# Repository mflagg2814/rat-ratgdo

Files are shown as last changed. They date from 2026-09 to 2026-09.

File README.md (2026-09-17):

# XIAO ESP32-C6 / ESP32-C5 board

> [!WARNING]
> **The XIAO ESP32-C6 board added in this fork has not been built or tested yet, and it is provided without support.** Use it at your own risk.

AI disclosure: Board layout is my own. AI was used for verification, documentation, schematic cleanup, and minor board cleanup.

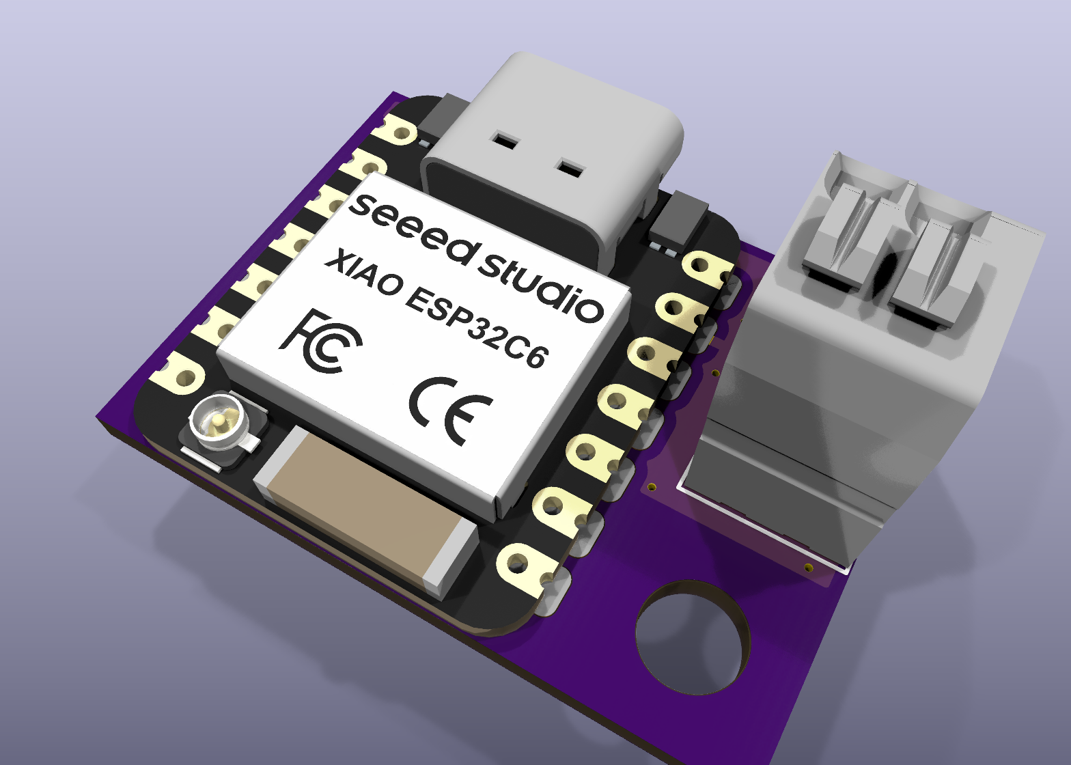
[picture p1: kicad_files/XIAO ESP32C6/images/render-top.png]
3D render of the XIAO ESP32-C6 board


[`kicad_files/XIAO ESP32C6`](kicad_files/XIAO%20ESP32C6) is a small Security+ 2.0 interface for the ESPHome `secplus_gdo` component, built around a surface-mounted Seeed XIAO ESP32-C6. Compared with the [D1 Mini - ESP32](kicad_files/D1%20Mini%20-%20ESP32) board it is based on:

- **MCU:** a XIAO ESP32-C6 replaces the D1 Mini ESP32. TX is on GPIO22 (D4) and RX on GPIO18 (D10). As before, the module is powered from its own USB port. The same footprint and pinout also accept a Seeed XIAO ESP32-C5 (see the [board README](kicad_files/XIAO%20ESP32C6/README.md#xiao-esp32-c5-compatibility) for the C5 substitutions).
- **RX:** a 10k pull-up to 3V3 is added, because the firmware does not enable an internal one.
- **Values:** the TX GPIO pulldown is 4.7k (was 10k), and the RED-to-ground bias is 100k (was 10k).
- **Protection:** a 15 V unidirectional TVS is added on the RED line.
- **Obstruction:** the black-wire sensing circuit is removed, since obstruction status is read from the serial protocol.
- **Terminal:** A single 2-pole WAGO push-button terminal replaces the 3-pole connector options. Accepts 20-24 AWG.

The folder includes a [BOM](kicad_files/XIAO%20ESP32C6/BOM.md) with DigiKey part numbers, a [schematic PDF](kicad_files/XIAO%20ESP32C6/c6gdo-schematic.pdf), and a [README](kicad_files/XIAO%20ESP32C6/README.md) with the full list of changes and the reasoning behind them. The project needs KiCad 10 and contains its own symbol, footprint and 3D-model libraries.

## XIAO ESP32-C5 compatibility
This board was designed for the XIAO ESP32-C6. The pinouts are also chosen for XIAO ESP32-C5 compatibility. I'm unsure of precedent for the GDO firmware- it may or may not function on C5.

## Firmware
Intended for use with SecPlus GDO firmware using the ESP-IDF framework.

An example ESPHome YAML would be an adaptation of `grgdov3-board-secplus-gdo-thread.yaml`, found [here](https://github.com/GelidusResearch/grgdo). Note that you will at a minimum need to remap the UART pins and change the board/variant to match.

---

# rat-ratgdo
RAGE
AGAINST
THE
RATGDO



Credit and inspiration for this work goes to [@rlowens](https://github.com/rlowens) to let me know that there are other technical folks out there who needed this other than myself.

## Overview
This is an open source schematic for the ratgdo, based on the v2.5 [ratgdo](https://github.com/PaulWieland/ratgdo) PCB and code but installed using the [ESPHome fork](ESPHome%20vs%20native%20ratgdo.md) of ratgdo.  This project was created to allow people who need a ratgdo solution for their garage door opener but either cannot, or choose not to, source the solution from Paul Wieland. It also ensures that the PCB can be recreated as and when the project maintainer gives up on the project (much like Chamberlain themselves might do with their MyQ Cloud Service) and stops selling PCBs. 

### You are expected to know how to create the described circuit using your own prototyping skills.  That is, this project is for people who can solder well and know how to read schematics

The ***basic*** PCB schematic shown here in the Readme does not describe any circuitry other than the serial line garage door control and obstruction sensor.  All other optional features provided by ratgdo can be reverse engineered as needed, or may already be solved by one of the schematics the community has uploaded!

 As of January 2023, there are now multiple sources for commercially sold ratgdo boards.  **However if you want to buy a pre-made ratgdo setup, we recommend purchasing one [from Paul Wieland](https://github.com/PaulWieland/ratgdo) so as to reward the original creator.**

PCB Link
_Simple basic schematic for a Wemos D1 Mini based module_

See images of a [working breadboard prototype](images/Breadboard_working.png) and the [subsequent soldered prototype using a D1 shield](images/Simple%20prototype%20using%20D1%20shield.jpg).  Both of these prototypes are using 2n7000 MOSFETs exclusively, but that is because they are prototypes and whether a 2n7000 will work for TX will depend greatly on who manufactured your 2n7000.  See the section below on needed components for context.

## Components needed for basic functionality
The basic schematic shown above assumes the use of through-hole components.  If you wish to use SMD components, please refer to the [FAQ](FAQ.md#what-if-i-want-to-use-sot-23-smd-components), and you can also check out the community-provided schematics, which include SMD-based designs.

For this basic design, aside from the obvious requirement of a [supported ESP-32 or ESP8266 board](Supported%20Boards.md) flashed with the [ESPHome version](https://github.com/ratgdo/esphome-ratgdo), you will need:
- 3x 10 kohm (kilo-ohm) resistors
- 1x 2n7000 MOSFET for the RX pin
- 1x AO3400A (soldered to a SOT23 to DIP adapter board) for the TX pin.

It is also recommended you aquire a suitable 3-post screw terminal and some red, white, and black wire for connecting to the door opener.  These connections are very low current, so you can get away with fairly thin wire.

**Note:**  You may **try** to use a 2n7000 MOSFETs for **both** RX and TX, however depending on the manufacturere of your 2n7000 and its production batch, it might not be 100% reliable for the TX circuit because the ~3v switching signal from the ESP8266 may not be enough to trigger the gate of the 2n7000.  There are many examples working using the 2n7000 however, so it might work.  If you have reliability issues for sending commands, we can only recommend you use the AO3400A SMD MOSFET, soldered to a SOT23-to-DIP adapter board.  

## INSTALL REQUIREMENTS
For both this basic schematic shown here in the Readme and how they it is laid out, you must use the ESPHome fork of ratgdo and - for ESP8266 based boards - select the "ratgdo v2.5x" image on the ESPhome [web installer page](https://ratgdo.github.io/esphome-ratgdo/).  For ESP32 based boards the above does not currently apply and you must use the v2.0 installer and follow our basic ESP-32 schematic we provide in the Supported Boards page.

For the ESP8266 based boards, if installing using Paul Wieland's native ratgdo installer and you install for a v2.0 board, you must wire your TX to D4 (GPIO2) rather than D1 (GPIO5).

## Having a PCB printed
You may use the files from the [schematics folder](kicad_files) to have your own PCB printed.  Shown is an example 3D render of an ESP32 based board using a Wemos ESP32 D1 board.

3D render of printed PCB
_An example of the D1 Mini ESP32 Wide Format_

Here is an example of a printed PCB with a raw ESP8266 and an LM2596 module, for being powered by a GDO with the battery backup capabilities.
Printed PCB using ESP8266 and LM2596
_An example of a PCB using a bare ESP8266 and LM2596 module_

### Schematic options
The community has provided a few options of schematic files suitable for sending to a PCB printing company.
- [Wemos D1 Mini ESP8266](kicad_files/D1%20Mini%20-%20ESP8266)
- [Wemos D1 Mini ESP32](kicad_files/D1%20Mini%20-%20ESP32) (massive overkill for ratgdo but it's your choice!)
- [Wemos D1 Mini ESP32 Wide Format](kicad_files/D1%20Mini%20Wide%20-%20ESP32)
- [Bare ESP8266 module](kicad_files/Bare%20ESP8266)
- [Seeed XIAO ESP32-C6](kicad_files/XIAO%20ESP32C6) (untested; KiCad 10; see the note at the top)

> If you just want to try ordering a board from somewhere like PCBWay, then check out the most recent [build artifacts](https://github.com/Kaldek/rat-ratgdo/actions/workflows/pcb.yaml)

## How the ratgdo circuit works
The ratgdo circuitry which we cover in this project consists of two sections; Garage Door control and obstruction sensors.

### Garage Door Control
#### Description of the Chamberlain configuration
The Chamberlain garage door control circuit is a two-wire setup consisting of a Ground, and a combined +12v power and serial data line.  The serial data line is held at 12v unless data transmission is occurring.  Data transmission is performed by pulling the 12v line down to GND for each data bit.  The benefit here is that a single wire can be used for providing power to door control panels and data transmssion on a single wire.  The use of appropriately sized capacitors in door control panels means they do not switch off during data transmission.

#### How ratgdo interfaces with the Chamberlain wiring
The ratgdo taps into the red control wire and uses this single wire for transmission of commands onto the serial bus, and for receiving data from the serial bus.  As it is a single wire protocol and operates half-duplex, the ratgdo circuitry uses N-channel MOSFETs wired in a manner which allows the ESP8266 to never transmit when the serial line is already low.

In operation, this means that the ratgdo is mostly listening to the serial bus to ensure it is keeping track of the state of the door.  For example, if the door is manually opened (or opened by use of the MyQ app even), these events are broadcast onto the serial bus by the door controller.  ratgdo is therefore able to know that the state of the door has changed.  In turn, this means that when controlling ratgdo via Home Assistant, the status of the door in HA is always up to date.

#### Wiring to Garage Door


### Obstruction sensor
The ratgdo monitors the real-time state of the obstruction sensors directly.  We assume this is because obstruction status is not broadcast in real time by the door controller, and safety is paramount.  It allows you to set up real-time alerts in Home Assistant for any time the door is obstructed.  The ratgdo taps into the obstruction sensor power wire which also acts as a communication bus, however the signalling is only an ongoing status of whether the obstruction sensors are working and whether there is an obstruction.

## Contributing
This is a fully open repo, in that we welcome any and all additions for all sorts of Edge Cases.  If you come up with something and would like it to be available to the community, raise a Pull Request and we'll work with you to get it published!

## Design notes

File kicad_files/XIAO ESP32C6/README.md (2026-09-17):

# Seeed XIAO ESP32-C6 / ESP32-C5 KiCad files

> [!WARNING]
> **This board has not been built or tested yet, and it is provided without support.** It passes KiCad's electrical rules check and design rules check, but it has never controlled a garage door. Use it at your own risk.

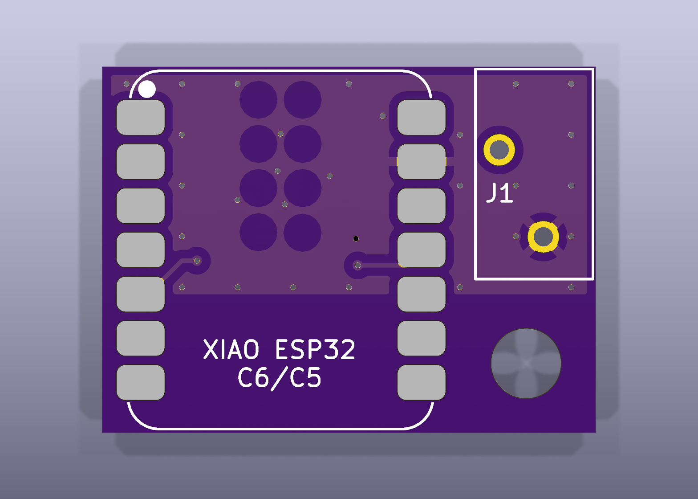
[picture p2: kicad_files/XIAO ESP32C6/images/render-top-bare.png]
Top view without the XIAO and terminal block
3D render, top
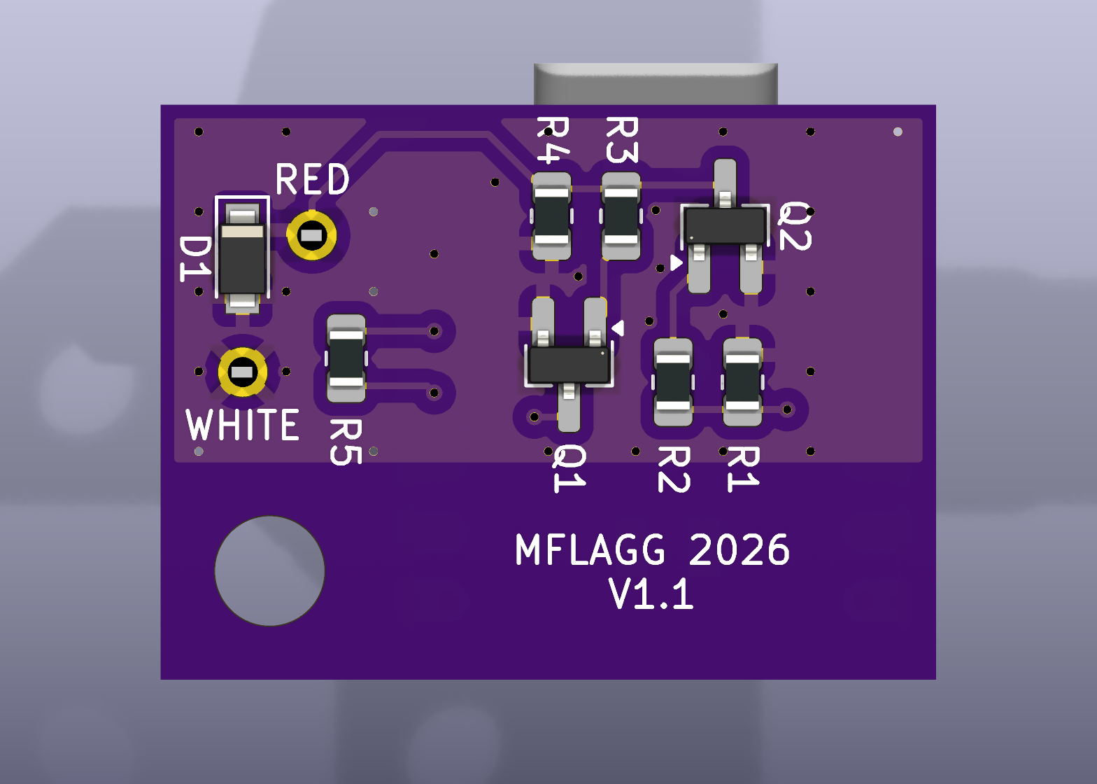
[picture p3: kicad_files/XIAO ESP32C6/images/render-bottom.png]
3D render, bottom


A small (28.4 × 21.05 mm, 2-layer) Security+ 2.0 interface based on this repository's D1 Mini - ESP32 board, built around a surface-mounted [Seeed Studio XIAO ESP32-C6](https://wiki.seeedstudio.com/xiao_esp32c6_getting_started/). It connects to only the RED and WHITE wall-control wires, and the XIAO is powered from its own USB-C port.

- Schematic: [c6gdo-schematic.pdf](c6gdo-schematic.pdf) (source: `c6gdo.kicad_sch`)
- Bill of materials: [BOM.md](BOM.md) / [BOM.csv](BOM.csv)

## Firmware

The board was designed for the ESPHome [`secplus_gdo`](https://github.com/gelidusresearch/esphome-secplus-gdo) component. That component inverts the UART, which matches the two inverting MOSFET stages on this board.

Obstruction status comes from the Security+ 2.0 serial protocol, so no obstruction pin is configured.

An example ESPHome YAML would be an adaptation of `grgdov3-board-secplus-gdo-thread.yaml`, found [here](https://github.com/GelidusResearch/grgdo). Note that you will at a minimum need to remap the UART pins and change the board/variant to match.

```yaml
substitutions:
  uart_tx_pin: GPIO22 # D4
  uart_rx_pin: GPIO18 # D10

esp32:
  board: seeed_xiao_esp32c6
  flash_size: 4MB
  variant: esp32c6
  framework:
    type: esp-idf
```

## XIAO ESP32-C5 compatibility

This board was designed for the XIAO ESP32-C6. The pinouts are also chosen for XIAO ESP32-C5 compatibility. I'm unsure of precedent for the GDO firmware- it may or may not function on C5.

If you populate a C5 instead of a C6, use this in place of the substitutions/esp32 block above:

```yaml
substitutions:
  uart_tx_pin: GPIO23 # D4
  uart_rx_pin: GPIO10 # D10

esp32:
  board: seeed_xiao_esp32c5
  flash_size: 8MB
  variant: esp32c5
  framework:
    type: esp-idf
```

## Changes from the D1 Mini - ESP32 board

The starting point is [`kicad_files/D1 Mini - ESP32`](../D1%20Mini%20-%20ESP32). The core of that design is kept as is:
- Q1 (2N7002) with a 10k series resistor into its gate for RX.
- Q2 (AO3400A) with a 1k gate resistor for TX.
- A pulldown on the TX GPIO.
- A bias resistor from RED to ground.
- No power circuitry on the board (the module is powered over its own USB).

The changes are:

| | D1 Mini - ESP32 | This board | Notes |
|-|-|-|-|
| MCU | Wemos D1 Mini ESP32: TX IO22 (D1), RX IO21 (D2) | Seeed XIAO ESP32-C6: TX GPIO22 (D4), RX GPIO18 (D10) | Smaller module with WiFi 6 / Thread. Neither pin is a C6 strapping pin, and neither conflicts with the console UART, USB-JTAG or the antenna switch. D4/D10 were chosen (instead of D3/D10) so the same board also works with a XIAO ESP32-C5 — see [XIAO ESP32-C5 compatibility](#xiao-esp32-c5-compatibility). |
| RX pull-up | None | **R5** 10k to 3V3 (new) | gdolib never enables an internal pull-up on the RX pin, so without R5 the pin floats when Q1 is off. |
| TX GPIO pulldown | 10k | **R1** 4.7k | Keeps Q2 off while the ESP32 is in reset. In reset the pin's ~45 kΩ internal pull-up is enabled, which with the old 10k pulldown would set Q2's gate to about 3.3 V × 10k / 55k ≈ 0.60 V. That is just under the AO3400A's minimum turn-on threshold of 0.65 V (0.65–1.45 V). With 4.7k the gate sits at about 0.31 V. |
| RED bias to ground | 10k | **R4** 100k | Lighter load on the opener's line: about 0.13 mA instead of 1.3 mA at 12.7 V. |
| Transient protection | None | **D1** PTVS15VS1UR 15 V, 400 W unidirectional TVS (new) | Clamps transients on the wire run to the opener. |
| Obstruction | IO23 through a 10k series resistor and 10k pulldown | Removed | Obstruction status is read from the Security+ 2.0 serial protocol. |
| Connector | Three 3-pole footprint options (5.00 mm screw terminal, 3.5 mm Phoenix MCV, 2.54 mm header) | One 2-pole WAGO 250-1402 push-button terminal | Only RED and WHITE are needed. Accepts 20-24 AWG. |

## Wiring and mounting

- **J1 RED** → opener's red wall-control terminal. **J1 WHITE** → opener's white terminal (ground). The labels are on the back silkscreen.
- Power the XIAO from any USB-C supply.
- Mount it with a #6-32 × 1" nylon screw through the 4.0 mm hole into a SnapSkru SPM Mini drywall anchor (see the BOM).
  - M3.5 should also work for the mounting screw.
  - I strongly recommend against a metallic screw in this position. It may interfere with the antenna.

## PCB notes

- The XIAO sits on the top side, flush with the bottom board edge. All other parts are on the back.
- The XIAO's underside pads (24–33) are **not soldered**. The footprint has no copper for them; instead it marks each one with an F.Fab outline and a rule area, so DRC flags any via placed there. The top-layer ground fill also stays out of these areas, so a flaw in the solder mask can't short a signal or power pad to ground. These pads are also left off the schematic symbol.
- Both copper layers are ground-filled, and both fills stop at y = 55 mm, leaving the board under the XIAO's antenna end free of copper.
- Stitching vias tie the two ground fills together. Most sit on a regular 3.2 mm grid, including a row along the fill edge nearest the antenna, with a few extra vias between the parts in the center. The spacing comes from the WiFi wavelength:
  - A 2.4 GHz signal has a wavelength (λ) of about 125 mm in air, or roughly 60–70 mm in FR4.
  - A common rule of thumb keeps stitching vias no more than λ/20–λ/10 apart, about 3–6 mm. That way no patch of copper is large enough to act as a resonator or slot antenna at WiFi frequencies.
  - On this board, no point where both layers are filled is more than about 3.2 mm from a stitching via.
- Under the XIAO's two rows of edge pads, only the bottom layer is ground-filled, since the top layer holds the pads. These bottom-only strips are about 4 mm wide. Each one is joined to the rest of the bottom fill along its full length, and a column of vias runs along its inner edge. So each strip is part of the ground plane rather than a separate flap, and it is far too small to resonate at 2.4 GHz (a quarter wavelength is about 15–17 mm in FR4).

## Project layout

Everything the project uses is inside this folder. Symbols, footprints and 3D models are referenced through `${KIPRJMOD}` via the project's own `sym-lib-table` and `fp-lib-table`, so the folder can be moved or renamed and opened on another machine without extra library setup.

```
c6gdo.kicad_pro / .kicad_sch / .kicad_pcb   KiCad 10 project
c6gdo-schematic.pdf                          schematic export
BOM.md, BOM.csv                              bill of materials
gerbers/                                     Gerber + Excellon drill files
c6gdo-gerbers.zip                            the same files, zipped for upload to a PCB fab
lib/c6gdo.kicad_sym                          project symbol library
lib/c6gdo.pretty/                            project footprint library
lib/c6gdo.3dshapes/                          3D models (STEP/IGES)
images/                                      3D renders
```

The files require **KiCad 10**. The Gerbers match the current board. After any board change, re-export them: copper, mask, paste, silkscreen and Edge.Cuts layers, plus separate PTH/NPTH Excellon drill files.

Sources:
- **XIAO symbol and footprint:** derived from Seeed Studio's official XIAO KiCad library.
- **XIAO 3D model** (`lib/c6gdo.3dshapes/seeed-studio-xiao-esp32c6-v2.step`): "[3D model for Seeed Studio XIAO ESP32C6](https://www.printables.com/model/1338408-3d-model-for-seeed-studio-xiao-esp32c6)" from Printables. It is licensed under [CC BY-SA 4.0](https://creativecommons.org/licenses/by-sa/4.0/) and included unmodified.
- **WAGO footprint and 3D model:** from the [250-1402 Ultra Librarian CAD download on DigiKey](https://www.digikey.com/en/models/15551338?tab=ultralibrarian).
- **Everything else:** the remaining footprints and 3D models come from the standard KiCad libraries.

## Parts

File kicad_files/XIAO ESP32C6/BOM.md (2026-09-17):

## BOM

The same data is in [BOM.csv](BOM.csv), which can be uploaded to DigiKey's BOM Manager. The symbols in the schematic also carry `Manufacturer`, `MPN` and `DigiKey PN` fields.

### Board

|Ref|Qty|Value|Description|Package|Manufacturer|MPN|DigiKey|
|-|-|-|-|-|-|-|-|
|U1|1|XIAO ESP32C6|ESP32-C6 module, standard (not pre-soldered) version|XIAO castellated SMD|Seeed Technology|113991254|[1597-113991254-ND](https://www.digikey.com/en/products/result?keywords=1597-113991254-ND)|
|J1|1|250-1402|PCB terminal block, push-button, 2-pole (RED, WHITE)|THT, 2.54 mm|WAGO|250-1402|[2946-250-1402-ND](https://www.digikey.com/en/products/result?keywords=2946-250-1402-ND)|
|D1|1|PTVS15VS1UR|TVS diode, unidirectional, 15 V standoff, 400 W (cathode to RED)|SOD-123W|Nexperia|PTVS15VS1UR,115|[1727-5315-1-ND](https://www.digikey.com/en/products/result?keywords=1727-5315-1-ND)|
|Q1|1|2N7002|N-ch MOSFET 60 V, RX level shifter. Needs a ±20 V gate rating, so do not substitute AO3400A|SOT-23|onsemi|2N7002|[2N7002NCT-ND](https://www.digikey.com/en/products/result?keywords=2N7002NCT-ND)|
|Q2|1|AO3400A|N-ch MOSFET 30 V, open-drain TX driver|SOT-23|Alpha & Omega|AO3400A|[785-1000-1-ND](https://www.digikey.com/en/products/result?keywords=785-1000-1-ND)|
|R1|1|4.7k|TX gate pulldown|0805|Panasonic|ERA-6AEB472V|[P4.7KDACT-ND](https://www.digikey.com/en/products/result?keywords=P4.7KDACT-ND)|
|R2|1|1k|Q2 gate series resistor|0805|Panasonic|ERA-6AEB102V|[P1.0KDACT-ND](https://www.digikey.com/en/products/result?keywords=P1.0KDACT-ND)|
|R3, R5|2|10k|Q1 gate series resistor / RX pull-up|0805|Panasonic|ERA-6AED103V|[P123794CT-ND](https://www.digikey.com/en/products/result?keywords=P123794CT-ND)|
|R4|1|100k|RED line bias|0805|Panasonic|ERA-6AEB104V|[P100KDACT-ND](https://www.digikey.com/en/products/result?keywords=P100KDACT-ND)|

The resistors are thin-film 0.1% / 0.5% parts. That is more precision than the circuit needs, but in single quantities they cost about the same as basic 1% parts, so any 0805 resistor of the same value will do.

### Mounting hardware

|Ref|Qty|Part|Manufacturer|MPN|Source|
|-|-|-|-|-|-|
|H1|1|#6-32 × 1" nylon pan head Phillips machine screw (6.68 mm head), through the 4.0 mm hole|Essentra Components|010632PW100|DigiKey [RPC7858-ND](https://www.digikey.com/en/products/result?keywords=RPC7858-ND)|
|-|1|SnapSkru SPM Mini self-drilling drywall anchor (3/8"–5/8" drywall, #6–#8 screws)|TOGGLER|SnapSkru SPM Mini|Hardware stores; not stocked by DigiKey|

The anchor is designed for coarse #6–#8 screws. A fine-thread #6-32 screw still bites into it, but it will hold less than the anchor's rated load. That is plenty for a board this light.

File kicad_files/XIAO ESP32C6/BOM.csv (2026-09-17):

Item | Reference | Qty | Value | Description | Package | Manufacturer | MPN | DigiKey PN | Notes
1 | U1 | 1 | XIAO ESP32C6 | ESP32-C6 WiFi6/BLE5/802.15.4 module | XIAO 14-pad castellated | Seeed Technology Co., Ltd | 113991254 | 1597-113991254-ND | Standard (non-pre-soldered) version; solder by castellated edges
2 | J1 | 1 | 250-1402 | PCB terminal block, push-button, 2-pole (RED + WHITE from GDO) | THT 2.54 mm pitch | WAGO Corporation | 250-1402 | 2946-250-1402-ND
3 | D1 | 1 | PTVS15VS1UR | TVS diode, unidirectional, 15 V standoff, 400 W | SOD-123W | Nexperia | PTVS15VS1UR,115 | 1727-5315-1-ND | Cathode to RED/CTRL
4 | Q1 | 1 | 2N7002 | N-ch MOSFET 60 V, RX level shifter | SOT-23 | onsemi | 2N7002 | 2N7002NCT-ND | Needs +/-20 V gate rating - do not substitute AO3400A
5 | Q2 | 1 | AO3400A | N-ch MOSFET 30 V, open-drain TX driver | SOT-23 | Alpha & Omega Semiconductor Inc. | AO3400A | 785-1000-1-ND
6 | R1 | 1 | 4.7k | Resistor 4.7 kOhm 0.1% 1/8 W, TX gate pulldown | 0805 | Panasonic Industry | ERA-6AEB472V | P4.7KDACT-ND
7 | R2 | 1 | 1k | Resistor 1 kOhm 0.1% 1/8 W, Q2 gate series | 0805 | Panasonic Industry | ERA-6AEB102V | P1.0KDACT-ND
8 | R3, R5 | 2 | 10k | Resistor 10 kOhm 0.5% 1/8 W, Q1 gate series / RX pull-up | 0805 | Panasonic Industry | ERA-6AED103V | P123794CT-ND
9 | R4 | 1 | 100k | Resistor 100 kOhm 0.1% 1/8 W, RED/CTRL bias | 0805 | Panasonic Industry | ERA-6AEB104V | P100KDACT-ND
10 | H1 | 1 | #6-32 x 1 in | Machine screw, pan head Phillips, nylon | Head 6.68 mm dia | Essentra Components | 010632PW100 | RPC7858-ND | Mechanical - not in schematic
11 | - | 1 | SnapSkru SPM Mini | Self-drilling drywall anchor, 3/8-5/8 in drywall, #6-#8 screws | Glass-filled nylon | TOGGLER (Mechanical Plastics) | SnapSkru SPM Mini |  | Not stocked by DigiKey
12 | PCB | 1 | c6gdo | Bare PCB, 28.4 x 21.05 mm | 2-layer 1.6 mm FR4

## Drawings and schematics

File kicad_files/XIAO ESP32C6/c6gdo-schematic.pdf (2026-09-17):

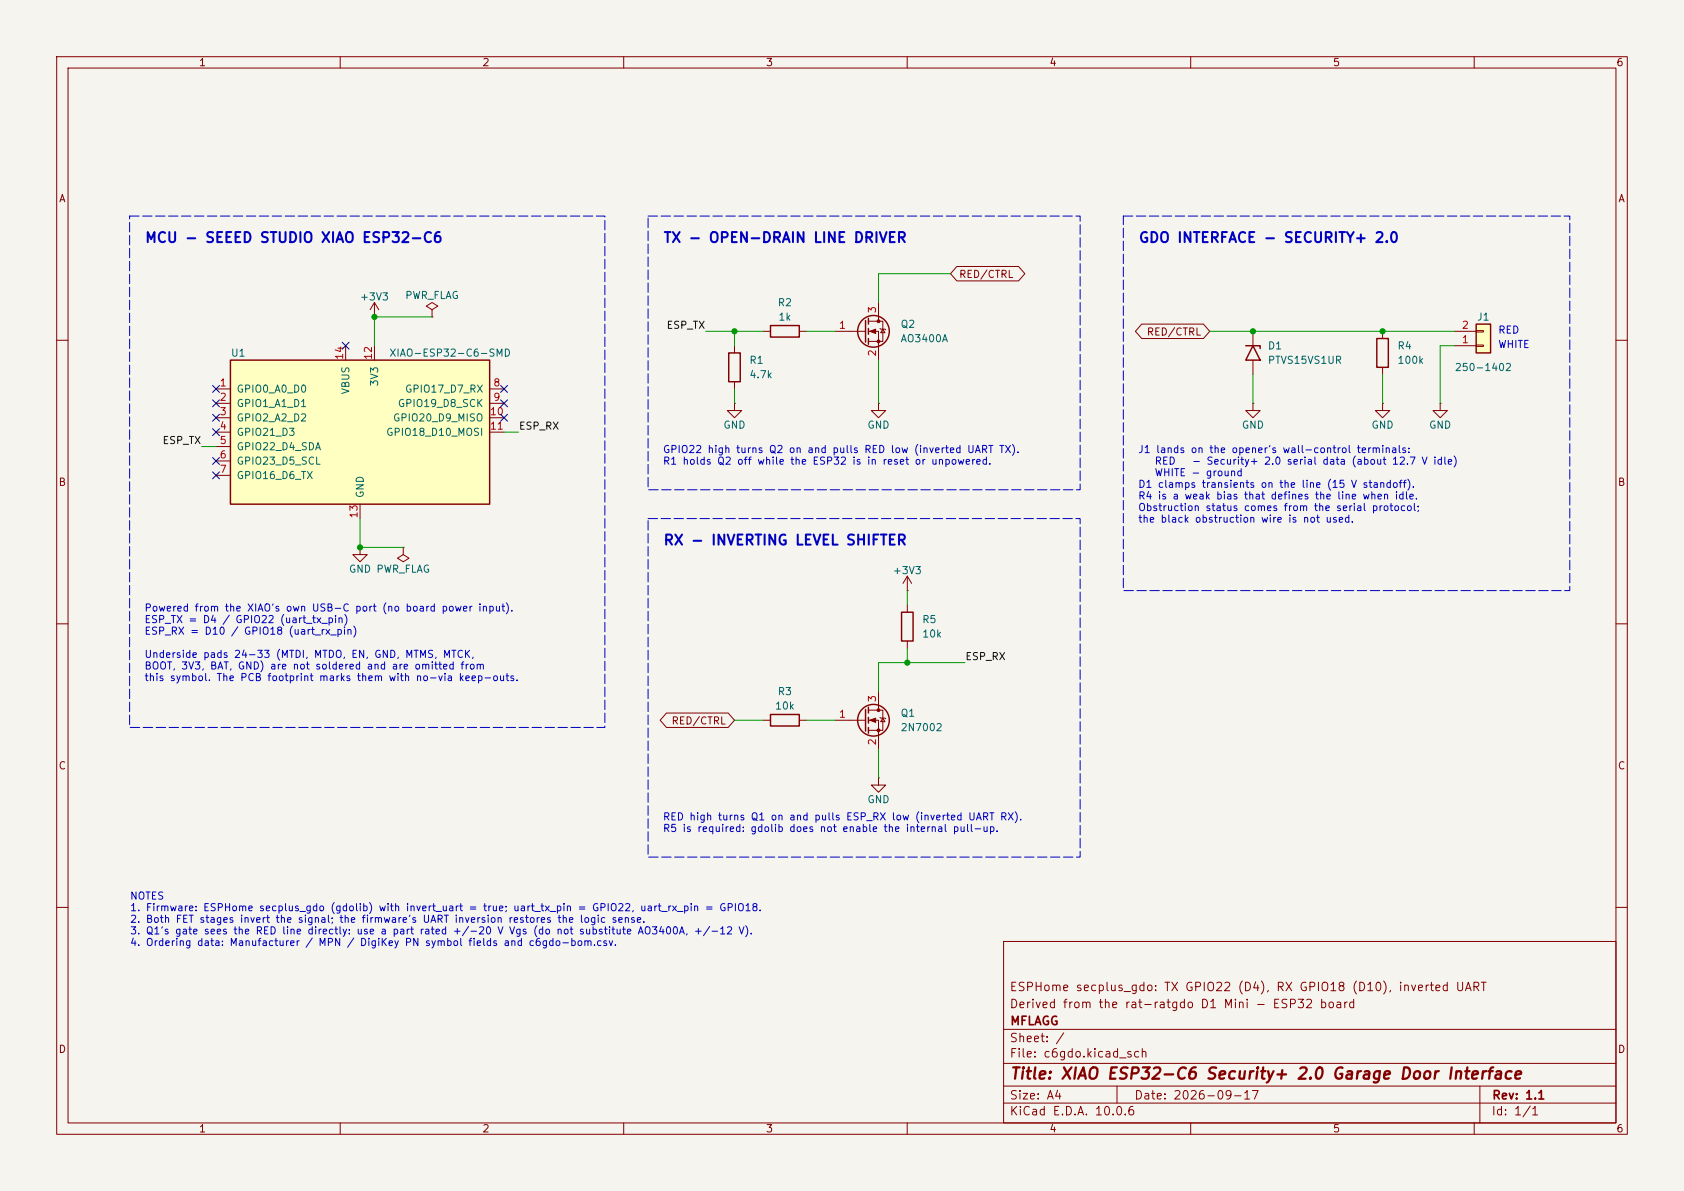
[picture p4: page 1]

MCU - SEEED STUDIO XIAO ESP32-C6

TX - OPEN-DRAIN LINE DRIVER

GPIO22 high turns Q2 on and pulls RED low (inverted UART TX). R1 holds Q2 off while the ESP32 is in reset or unpowered.

RX - INVERTING LEVEL SHIFTER
10k GND

ESPHome secplus_gdo: TX GPIO22 (D4), RX GPIO18 (D10), inverted UART GND

Powered from the XIAO's own USB-C port (no board power input). ESP_TX = D4 / GPIO22 (uart_tx_pin) ESP_RX = D10 / GPIO18 (uart_rx_pin) Underside pads 24-33 (MTDI, MTDO, EN, GND, MTMS, MTCK,

BOOT, 3V3, BAT, GND) are not soldered and are omitted from
this symbol. The PCB footprint marks them with no-via keep-outs.

1. Firmware: ESPHome secplus_gdo (gdolib) with invert_uart = true; uart_tx_pin = GPIO22, uart_rx_pin = GPIO18. 2. Both FET stages invert the signal; the firmware's UART inversion restores the logic sense. 3. Q1's gate sees the RED line directly: use a part rated +/-20 V Vgs (do not substitute AO3400A, +/-12 V). 4. Ordering data: Manufacturer / MPN / DigiKey PN symbol fields and c6gdo-bom.csv.

Derived from the rat-ratgdo D1 Mini - ESP32 board
MFLAGG
Sheet: /
File: c6gdo.kicad_sch
Title: XIAO ESP32-C6 Security+ 2.0 Garage Door Interface

Size: A4 | Rev: 1.1
KiCad E.D.A. 10.0.6 | Id: 1/1

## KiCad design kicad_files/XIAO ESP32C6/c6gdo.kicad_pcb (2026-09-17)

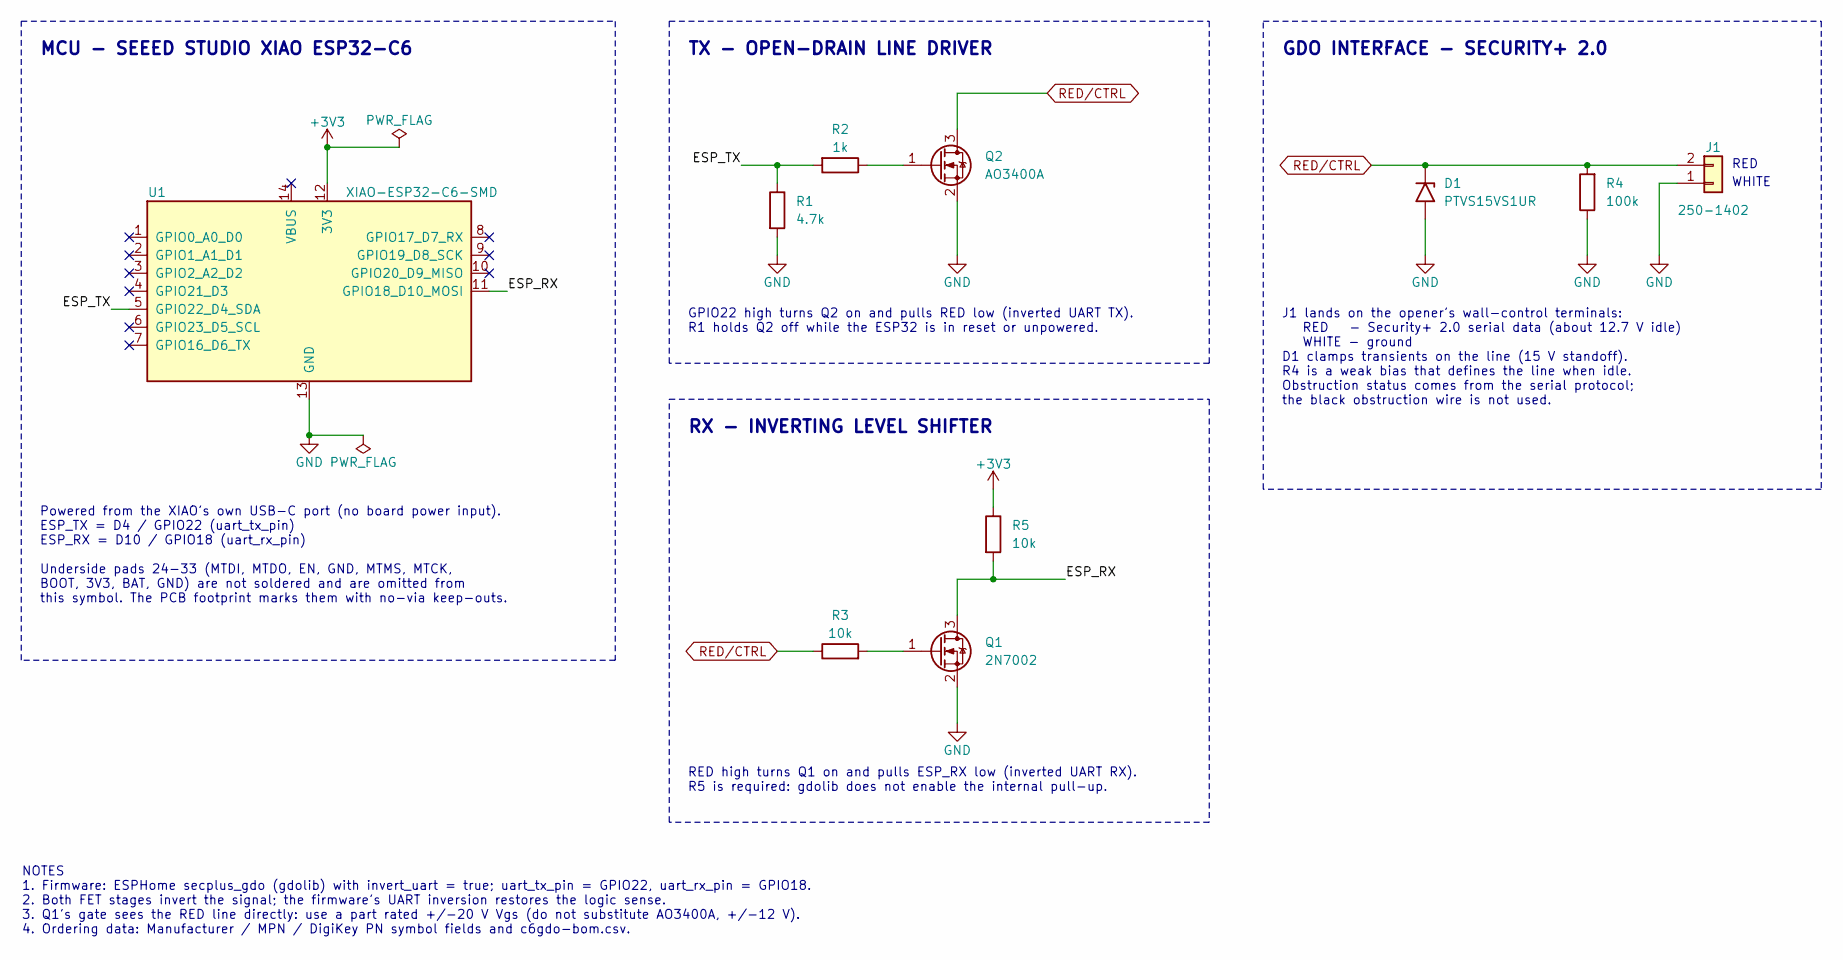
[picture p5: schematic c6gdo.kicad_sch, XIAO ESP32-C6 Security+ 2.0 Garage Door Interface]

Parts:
D1: PTVS15VS1UR; Nexperia_CFP3_SOD-123W; MPN PTVS15VS1UR,115; DigiKey PN 1727-5315-1-ND
J1: 250-1402; CONN2_250-1402_WAG; MPN 250-1402; DigiKey PN 2946-250-1402-ND
Q1: 2N7002; SOT-23_Handsoldering; MPN 2N7002; DigiKey PN 2N7002NCT-ND
Q2: AO3400A; SOT-23_Handsoldering; MPN AO3400A; DigiKey PN 785-1000-1-ND
R1: 4.7k; R_0805_2012Metric_Pad1.20x1.40mm_HandSolder; MPN ERA-6AEB472V; DigiKey PN P4.7KDACT-ND
R2: 1k; R_0805_2012Metric_Pad1.20x1.40mm_HandSolder; MPN ERA-6AEB102V; DigiKey PN P1.0KDACT-ND
R3, R5: 10k; R_0805_2012Metric_Pad1.20x1.40mm_HandSolder; MPN ERA-6AED103V; DigiKey PN P123794CT-ND
R4: 100k; R_0805_2012Metric_Pad1.20x1.40mm_HandSolder; MPN ERA-6AEB104V; DigiKey PN P100KDACT-ND
U1: XIAO-ESP32-C6-SMD; MPN 113991254; DigiKey PN 1597-113991254-ND

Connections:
+3V3: R5.1, U1.12 (3V3)
/ESP_RX: Q1.3 (D), R5.2, U1.11 (GPIO18_D10_MOSI)
/ESP_TX: R1.1, R2.2, U1.5 (GPIO22_D4_SDA)
GND: D1.2 (A), J1.1, Q1.2 (S), Q2.2 (S), R1.2, R4.1, U1.13 (GND)
unnamed: Q1.1 (G), R3.2
unnamed: Q2.1 (G), R2.1
RED/CTRL: D1.1 (K), J1.2, Q2.3 (D), R3.1, R4.2

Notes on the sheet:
GPIO22 high turns Q2 on and pulls RED low (inverted UART TX). R1 holds Q2 off while the ESP32 is in reset or unpowered.
J1 lands on the opener's wall-control terminals: RED - Security+ 2.0 serial data (about 12.7 V idle) WHITE - ground D1 clamps transients on the line (15 V standoff). R4 is a weak bias that defines the line when idle. Obstruction status comes from the serial protocol; the black obstruction wire is n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
NOTES 1. Firmware: ESPHome secplus_gdo (gdolib) with invert_uart = true; uart_tx_pin = GPIO22, uart_rx_pin = GPIO18. 2. Both FET stages invert the signal; the firmware's UART inversion restores the logic sense. 3. Q1's gate sees the RED line directly: use a part rated +/-20 V Vgs (do not substitute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
RX - INVERTING LEVEL SHIFTER
RED high turns Q1 on and pulls ESP_RX low (inverted UART RX). R5 is required: gdolib does not enable the internal pull-up.
WHITE
RED
MCU - SEEED STUDIO XIAO ESP32-C6
GDO INTERFACE - SECURITY+ 2.0
TX - OPEN-DRAIN LINE DRIVER
Powered from the XIAO's own USB-C port (no board power input). ESP_TX = D4 / GPIO22 (uart_tx_pin) ESP_RX = D10 / GPIO18 (uart_rx_pin) Underside pads 24-33 (MTDI, MTDO, EN, GND, MTMS, MTCK, BOOT, 3V3, BAT, GND) are not soldered and are omitted from this symbol. The PCB footprint marks them with no-v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

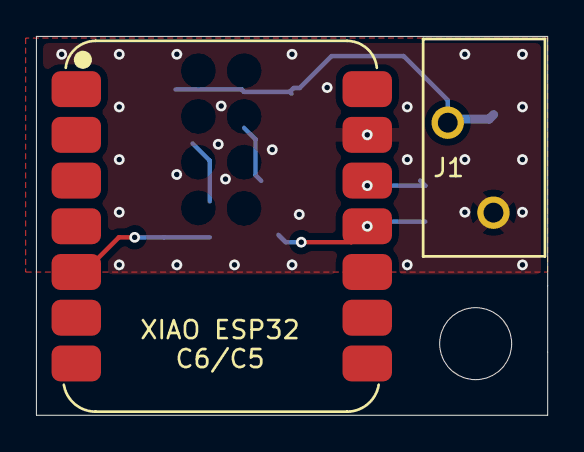
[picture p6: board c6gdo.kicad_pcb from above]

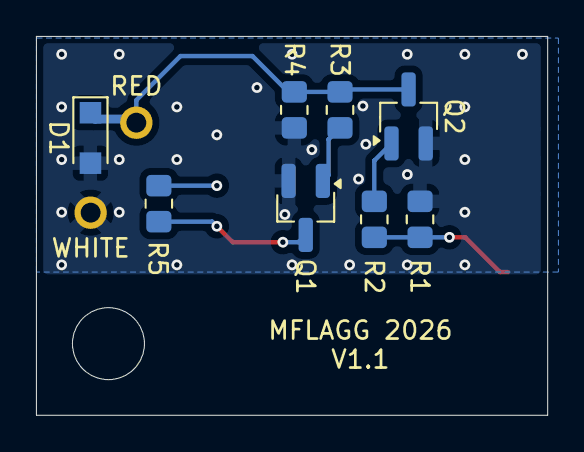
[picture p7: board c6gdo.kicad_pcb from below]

Board: 2 copper layers, 28.4 x 21.0 mm, 11 parts (8 on the bottom side), 7 nets.

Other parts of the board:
H1: MountingHole_4mm

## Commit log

2026-09-16 Initial Xiao ESP32C6 board
    [BOM.csv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]
2026-09-16 Increase D1 pad size
    [c6gdo-B_Cu.gbr, c6gdo-B_Mask.gbr, c6gdo-B_Paste.gbr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]
2026-09-16 Remove copper under middle C6 pads
    [c6gdo-B_Cu.gbr, c6gdo-B_Mask.gbr, c6gdo-B_Paste.gbr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]
2026-09-17 Add C5 support
    [c6gdo-B_Cu.gbr, c6gdo-B_Mask.gbr, c6gdo-B_Paste.gbr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]
2026-09-17 D1 with better clamping voltage
    [BOM.csv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]
2026-09-21 Case note in README
